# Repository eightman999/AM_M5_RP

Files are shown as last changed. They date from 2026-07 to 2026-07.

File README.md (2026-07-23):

# AM_M5_SEN0628_x3_0pm50_CorridorAvoid

M5StickC Plus + Arduino Mega + SEN0628(8x8 ToF)x3 + BMA400 構成の、通路追従・障害物回避スキッドステアロボット。

## 概要

- 前方/左右(0°, +50°, -50°)に取り付けた3基のSEN0628(8x8マトリクスToF)で周囲を計測し、
  M5StickC Plus側で回避・通路中央維持・コーナー旋回を判断する。
- 駆動はArduino Megaが担当し、M5からUART経由で受け取った左右デューティ指令を
  L298N経由でモーターに出力する(500HzソフトウェアPWM、キック/ランプ制御付き)。
- M5側はWi-Fi SoftAPで点群・姿勢・加速度をUDP配信し、PC側の`tools/point_cloud_viewer.py`で
  リアルタイムに可視化(点群マップ・推定軌跡・ステータス表示)できる。

## ハードウェア構成

### 主要部品

| 部品 | 役割 |
|---|---|
| M5StickC Plus | メイン制御(判断・IMU・センサー統合・Wi-Fi配信) |
| Arduino Mega | モーター駆動専用(L298N制御、500Hz PWM) |
| SEN0628 (DFRobot 8x8 ToF) x3 | 前方/左右の距離計測(TCA9548A経由) |
| TCA9548A | I2Cマルチプレクサ(センサー3基+BMA400をチャンネル分離) |
| BMA400 (Seeed Grove, ±16g) | 補助加速度計(TCA CH0)。M5内蔵IMUとブレンドして点群ビューアーの位置推定に使用 |
| L298N | モータードライバ |

`robot-parts-all.3mf` / `robot-parts-all.stl` に3Dプリント用の車体パーツ一式が入っている。

### 配線

**TCA9548A チャンネル割当**(実機確認済み):

| チャンネル | 接続先 |
|---|---|
| CH0 | BMA400 (Grove, I2C 0x15) - コネクタは車体後ろ向き |
| CH1 | SEN0628 front (0°, 中央) |
| CH2 | SEN0628 left (+50°, ひだり) |
| CH3 | SEN0628 right (-50°, 右) |

**M5StickC Plus側I2Cバス**(2系統を`Wire.begin()`の切り替えで使い分け):

| バス | ピン | 用途 |
|---|---|---|
| 内蔵(body) | SDA=21, SCL=22 | M5内蔵IMU(MPU6886) |
| 外部(external) | SDA=32, SCL=33 | TCA9548A(SEN0628 x3 + BMA400) |

**M5 ⇔ Mega UART**(115200bps):

```
M5 GPIO26 TX  -> AM D19 RX1
AM D18 TX1    -> level shifter/divider -> M5 GPIO36 RX
GND common
```

**Mega ⇔ L298N**:

```
L298N IN1 -> AM D22 / PA0
L298N IN2 -> AM D23 / PA1
L298N IN3 -> AM D24 / PA2
L298N IN4 -> AM D25 / PA3
```

## ソフトウェア構成

| ファイル | 対象 | 内容 |
|---|---|---|
| `M5_AM_SEN0628_3xSEN0628_v15/M5_AM_SEN0628_3xSEN0628_v15.ino` | M5StickC Plus | センサー統合・判断ロジック・モーター指令送信・UDP点群配信(v23時点) |
| `AM_HighTorqueAntiStall_500HzPWM_NoJumper_v4_for_x3/AM_HighTorqueAntiStall_500HzPWM_NoJumper_v4_for_x3.ino` | Arduino Mega | モーター駆動専用(500Hz PWM、キック/ランプ、UARTでM5から受信)(v2時点) |
| `tools/point_cloud_viewer.py` | PC(Python) | UDP点群・IMU/加速度・推定軌跡・キャリブレーション進行状況のリアルタイム可視化ツール |
| `PARAMETERS.md` | - | 全チューニング定数の意味・調整効果の詳細解説 |

ファイル名の`_v15`/`_v4`はスケッチ内の初出バージョンを指すが、実際の版数は各ファイル冒頭の
changelogコメント(現時点でM5側はv23、Mega側はv2)を参照すること。

### 通信プロトコル(UDP点群配信)

- SoftAP: SSID `M5_POINT_CLOUD` / パスワード `m5pointcloud` / ポート `4210`
- フレームは`PCLD`マジック+CRC16-CCITT付きバイナリ。`version`フィールドで後方互換:
  - v1: 距離・姿勢の基本情報のみ
  - v2: + M5内蔵IMU加速度、センサー個別ヨー/タイムスタンプ
  - v3: + BMA400(TCA CH0)加速度。M5内蔵IMUと単純平均でブレンドして位置推定に利用
  - v4: + キャリブレーション(BtnB)の進行状況(`trimMilli`/`calRound`/`calPass`/`calDriftCdeg`)。
    `driveState`に`DS_CALIBRATING(3)`を追加し、キャリブ中はPC側ビューアーの
    「CALIBRATION」パネルにラウンド/パス/ドリフト/トリムをリアルタイム表示する
- 詳細なフィールド定義は`tools/point_cloud_viewer.py`の`PointCloudFrame`/`decode_frame()`、
  および送信側は`.ino`の`PointCloudFrame`構造体/`streamPointCloud()`を参照。

## セットアップ

### 必要なArduinoライブラリ

- M5StickCPlus
- DFRobot_MatrixLidar (SEN0628用)
- Seeed_BMA400 (`https://github.com/Seeed-Studio/Grove_3Axis_Digital_Accelerometer_BMA400`)
- 標準搭載: Wire, Preferences, WiFi, WiFiUdp

### 書き込み手順

1. `M5_AM_SEN0628_3xSEN0628_v15/M5_AM_SEN0628_3xSEN0628_v15.ino` をM5StickC Plusへ書き込み。
2. `AM_HighTorqueAntiStall_500HzPWM_NoJumper_v4_for_x3/AM_HighTorqueAntiStall_500HzPWM_NoJumper_v4_for_x3.ino` をArduino Megaへ書き込み。
3. 起動時、M5のLCDにセンサー初期化状況(SEN0628 3基、BMA400)が順に表示される。
   `not found` / `NG` 表示が出た場合は配線・TCAチャンネルを確認する。

### PC側ツールの実行

```
python3 tools/point_cloud_viewer.py
python3 tools/point_cloud_viewer.py --self-test   # ユニットテスト(プロトコルデコード・デッドレコニング)
```

PCをM5の SoftAP(`M5_POINT_CLOUD`)に接続してから起動する。追加の依存パッケージは無し(標準ライブラリのみ、tkinter必須)。

## 操作方法

- **BtnA**: IMUゼロ点校正 → 走行開始
- **BtnB**(停止中のみ): 直進キャリブレーション(v18)。短いパス(約3.3秒)を3回走って
  中央値ドリフトから左右モーター差(motorTrim)を算出しNVSへ保存。`CAL_OK_DEG`に収まるまで
  最大12ラウンド自動継続し、ラウンド間は「Reposition robot / B:continue A:stop」表示で
  ロボットを開始位置へ戻すよう案内する(後方無センサのため自動バックはしない)
- **BtnA+BtnB**(待機中): `drive`名前空間のNVSを初期化し、保存済みmotorTrimを0へ戻す
- 走行中はIMU方位維持+距離センサーによる連続ステア回避(v20)/バック/通路中央維持を自動判断。
  常に前進し続け、超信地旋回(その場旋回)は行わない
- LCDに状態(FORWARD/BACK)、理由、距離、トリム値などをリアルタイム表示

## 既知の課題・未検証事項

- **BMA400の軸対応**: コネクタが車体後ろ向きという情報とSeeed製品ページの座標系図から
  X=車体右/Y=車体前方と結論づけたが、実機での重力方向テスト(静止時Z≒+1000mg等)による
  裏取りはまだ行っていない。
- **M5側ファームウェア(BMA400関連コード)は実機コンパイル・書き込み未検証**
  (開発環境にArduino向けビルドツールチェーンが無いため、構文レビューのみ)。
- **v20: 超信地旋回(PIVOT)を全廃止し、常時前進+連続ステア(目標ヨーの連続バイアス)のみで
  回避する方式に変更した。実機での回避挙動確認はまだ行っていない。** 差動ステアは
  `HEADING_CORR_LIMIT`で頭打ちになるため、旧来のその場旋回よりも実効的な旋回半径が
  大きく、狭いコース・直角コーナーでは壁に接触するリスクがある。これに合わせて
  `FWD_CMD`/`FWD_SLOW_CMD`も減速したが、それでも足りない場合はさらなる調整が必要
  (詳細はPARAMETERS.md 1.4節参照)。低速・監視下での初回テストを推奨する。
- **v22: 上記の懸念(前方に壁が迫った時に曲がりきれない)への対策として、前方が実際に危険域
  (frontRed)の間だけ片輪を止める急旋回(タンクターン、逆転はしない)を追加した。実機での
  効き確認はまだ行っていない。**
- **v23: ユーザーフィードバックによる調整。** (1) WiFiはv21で試した既存WiFi(STA)接続を撤回し
  SoftAP方式に戻した(学校WiFi等、認証情報を書き込むのが望ましくない環境を考慮)。
  (2) 走行速度をさらに減速(`FWD_CMD` 180→165, `FWD_SLOW_CMD` 165→155)。
  (3) キャリブレーション中の前方ToFスペースチェックを廃止し、パスは常にフル尺で走る
  (コース長は運用者側で確保する前提)。(2)(3)とも実機での効果確認はまだ行っていない。
- **点群ビューアーのデッドレコニング**: v20でピボット自体が無くなったため「ピボット中は
  並進ゼロ扱い」のロジックは通常到達しなくなったが、コード自体は残っている(無害)。
  それとは別に、絶対位置補正(スキャンマッチング/ICP等)は引き続き未実装で、
  IMU/加速度ドリフトが蓄積する点は変わらない。
- **v16で変更したキャリブレーションゲイン**(`CAL_TRIM_GAIN`, `AUTO_TRIM_RATE`)は
  静的コードレビューに基づく変更で、実走行での再調整前提(詳細はPARAMETERS.md参照)。
- **v18の複数パス平均・自動ラウンド継続キャリブレーションは実機での収束確認がまだ**。
  1ラウンドの合計走行距離は旧来の単発10秒とほぼ同じになるよう設計したが、
  実際のコース長で問題なく収まるかは要確認。
- **v19のキャリブレーション情報UDP配信・点群ビューアーのCALIBRATIONパネルも実機未検証**
  (Pythonデコード側はセルフテスト済みだが、M5側からの実送信・表示は未確認)。
- センサー高さ・車体の静止傾き(前方1〜2度上向き)による遠方誤判定の可能性は理論上残っている
  (実測での数値補正は未実装)。

## 詳細パラメータ

各定数の意味・調整時の挙動変化・相互依存関係は [PARAMETERS.md](PARAMETERS.md) を参照。

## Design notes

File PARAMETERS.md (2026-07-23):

# パラメーター解説

対象:
- `M5_AM_SEN0628_3xSEN0628_v15/M5_AM_SEN0628_3xSEN0628_v15.ino`（M5StickC Plus, 判断・センサー統合側, v16時点)
- `AM_HighTorqueAntiStall_500HzPWM_NoJumper_v4_for_x3/AM_HighTorqueAntiStall_500HzPWM_NoJumper_v4_for_x3.ino`（Arduino Mega, モーター駆動側, v2時点)

値はソース内の定義そのまま。**「調整の効果」列は挙動の傾向を説明するものであり、数値の正しさは実走行で確認すること。**特に「テスト値+40mm」と注記のある距離閾値は、卓上ベンチテストの実測値に安全マージンを足した運用値であり、コース(壁間隔・障害物サイズ)が変わればテストからやり直す前提。

---

## 1. M5側 (M5StickC Plus)

### 1.1 通信・センサー基本設定

| 定数 | 値 | 意味 | 調整の効果 |
|---|---|---|---|
| `AM_UART_BAUD` | 115200 | M5⇔Mega間UARTのボーレート | Mega側`Serial1.begin(115200)`と必ず一致させる |
| `TCA_ADDR` | 0x70 | I2Cマルチプレクサ(TCA9548A系)のアドレス | 実機のTCAアドレスが異なれば要変更 |
| `SEN_COUNT` | 3 | SEN0628の搭載数 | 増減時は`SEN_CH`/`SEN_ANGLE_DEG`/`senDev`配列も要同時変更 |
| `SEN_CH` | {1,2,3} | 各センサーのTCAチャンネル番号(front/left/right) | 実機配線に合わせる(CH0はBM予約で未使用) |
| `SEN_ANGLE_DEG` | {0, +50, -50} | 各センサーの水平マウント角(車体前方基準) | 前方/側方への幾何投影(`senCosAbs`/`senSinAbs`)に直結。実機取付角とズレると全ての距離判定が狂う |
| `SEN0628_ADDR` | 0x33 | SEN0628本体のI2Cアドレス | センサー側設定変更時のみ変更 |
| `POLL_SEQ` | {0,1,2,0,1,2} | センサーのポーリング順(v16: 前方偏重4:2:2→均等1:1:1に変更) | 増やす=そのセンサーの鮮度が上がる。前方の比率を下げすぎると`SENSOR_STALE_MS`との兼ね合いで前方安全マージンが減る可能性 |
| `AM_COMMAND_PERIOD_MS` | 16 | Megaへモーター指令を送る最小間隔 | 短くすると指令送信頻度は上がるが`sendDriveCommandSmooth`のslewは別途`CMD_SLEW_PER_SEND`で制御される |
| `AM_TIMEOUT_MS` | 300 | Megaからのテレメトリが途絶えたと判断するまでの時間 | Mega側`TELEMETRY_PERIOD_MS`(35ms)より十分大きく保つこと |
| `TEST_MODE` | false | 加速度診断(衝撃検知等)の計算・表示を有効化するフラグ | trueにすると`lastImpactG`等がTEST_MODE時のみ計算される(実走行の判断には使われない、表示専用) |

### 1.2 車体形状・安全マージン

| 定数 | 値 | 意味 | 調整の効果 |
|---|---|---|---|
| `BODY_FRONT_MARGIN_MM` | 40 | 前方の当たり判定余裕(表示・内訳用) | 実際の閾値は各`FRONT_*_MM`に直接明示されているため、この値自体は現状ドキュメント的な意味合いが強い |
| `BODY_SIDE_MARGIN_MM` | 25 | 側方の当たり判定余裕(表示・内訳用) | 同上 |
| `EXTRA_SAFETY_MM` | 20 | 不確実性ぶんの追加余裕(表示・内訳用) | 同上 |
| `SENSOR_TO_TIRE_OUTER_MM` | 50 | 左右センサー位置からタイヤ外端までの張り出し | `sideClearanceMm()`でこの分を差し引いてタイヤ外端基準のクリアランスに変換。実車体で測り直した値に更新すること |

### 1.3 走行速度

| 定数 | 値 | 意味 | 調整の効果 |
|---|---|---|---|
| `FWD_CMD` | 155（v42: 140→155） | 通常前進の最大デューティ | 幅約1mのコースに合わせて一段増速 |
| `FWD_SLOW_CMD` | 135（v42: 120→135） | 減速時の下限デューティ | 回避距離を同時に拡大したうえで一段増速 |
| `MIN_MOVING_CMD` | 110（v26: 140→110） | 前進の正方向指令の最低デューティ(底上げ) | Mega側`MIN_EFFECTIVE_CMD`(100)に10の余裕を持たせた |
| `MAX_MOVING_CMD` | 252 | 送信可能な最大デューティ(飽和防止で255未満) | キャリブ走行(`CAL_DRIVE_CMD`)にも使われる |
| `TURN_CMD` | 210（v28新規） | 前方赤時の片輪停止旋回専用出力 | 通常減速値120では避けきれなかったため強化。片輪停止旋回では`motorTrim`を適用しない |
| `CLOCKWISE` | true（v33新規） | 四角での周回方向 | `true`なら時計回り＝右90°、`false`なら反時計回り＝左90° |
| `CORNER_TURN_DEG` | 90°（v33新規） | 四角検知時のIMU目標旋回角 | 旋回開始時ヨーから設定方向へ90° |
| `CORNER_TURN_DONE_DEG` | 5° | 90°旋回の終了許容差 | 目標まで5°以内で旋回完了 |
| `CORNER_CONFIRM_MS` / `CORNER_CONFIRM_FRAMES` | 200ms / 2フレーム（v34新規） | 前方赤を四角として確定する条件 | 同じキャッシュ値だけでは確定せず、異なる前方測距フレームが2回連続で赤かつ200ms継続した場合のみ90°旋回する |
| `CORNER_FRONT_X_MIN_MM` / `MAX` | 70mm / 320mm（v35新規） | 幾何四角判定で前方壁を探す車体前方範囲 | 各点を`x=L*cos(theta)`へ変換して探索 |
| `CORNER_FRONT_MIN_SPAN_MM` / `MIN_POINTS` | 140mm / 8点 | 前方を横切る壁とみなす最小横幅・点数 | 細い障害物や単発点を四角から除外する |
| `CORNER_FRONT_Y_BIN_MM` / `MIN_CONTIGUOUS_MM` | 50mm / 400mm（v36新規） | 前方壁として必要な横方向の連続占有幅 | 最大幅300mmの障害物前面を除外する。障害物の左右に後壁が見えても中央の欠落で連続判定が分断される |
| `CORNER_SIDE_MIN_SPAN_MM` / `MIN_POINTS` | 50mm / 6点（v37: 100→50） | コーナー外周側壁とみなす最小前後長・点数 | 幅1m中央では外周壁が約400mm横にあり、前方壁直前で視野に入る側壁長が約58mmになるため |
| `CORNER_SIDE_Y_MIN_MM` / `MAX` | 80mm / 600mm（v37: 上限380→600） | 幾何四角判定で外周側壁を探す左右距離範囲 | 幅約1mのコース中央から見える約400〜500mm先の外周壁を含める |
| `COURSE_RETURN_DONE_DEG` / `COURSE_RETURN_TIMEOUT_MS` | 3° / 2000ms（v34新規） | 通常回避後に元の直進方位へ戻す終了条件 | 3°以内へ戻るか2秒経過で復帰処理を終了する。90°コーナー旋回には適用しない |
| `CENTER_OBS_SCORE_DELTA_MAX` | 15（v43新規） | 中央障害物とみなす左右危険スコアの最大差 | 左右がほぼ同程度に見える前方障害物だけを対象にする |
| `CENTER_OBS_CLEARANCE_DELTA_MAX_MM` | 50mm（v43新規） | 中央障害物とみなす左右クリアランスの最大差 | L字でなく左右差50mm以内なら周回設定方向へ固定回避する |
| `VEHICLE_WIDTH_MM` | 300mm（v44新規） | 中央障害物回避時の通過可否基準 | 規定旋回側が300mm未満で、反対側に300mm以上あれば反対側へ回避する |
| `SEN_SIDE_DANGER_MM` / `SEN_SIDE_WARN_MM` | 130mm / 230mm（v45新規） | 左右8x8点群専用の危険・警戒値 | 前方用160/280mmと分離し、前方の半透明板感度を維持する |
| `FORCE_BACK_MS` / `BACK_CLEAR_CONFIRM_MS` | 3000ms / 300ms（v46） | 通常バック時間と、バック後の前方安全確認時間 | 3秒終了時も前方赤なら停止を維持し、赤解除が300ms続くまで前進しない |
| SEN0628 `raw[64]`読取バッファ | 毎フレーム全セルを0クリア（v47） | 未更新セルの前回値を無効化 | `getAllData()`前に消去し、残留した近距離値による赤判定を防ぐ |
| `SEN_FRONT_ROW_FIRST` / `SEN_FRONT_ROW_LAST` | row 1〜3（v48） | 前方センサーの走行判定使用行 | 床側に映るrow 4〜5を前方の赤・バック判定から除外する。左右はrow 2〜5を維持 |

### 1.4 連続ステア回避判定(v20: 超信地旋回を全廃止)

v16まではLCD赤判定/距離閾値で超信地旋回(その場で停止して回転)を開始し、IMU旋回角で終了判定する
方式だった。v20でこれを全廃止し、**常に前進しながら**危険度スコア(0-100)に応じて目標ヨー
(`targetYawDeg`)を連続的に「広い側/安全な側」へバイアスする方式に一本化した。実際の差動出力は
既存の`headingCorrection()`(±`HEADING_CORR_LIMIT`)がそのまま担うため、新規の差動計算は無い。

| 定数 | 値 | 意味 | 調整の効果 |
|---|---|---|---|
| `STEER_MAX_DEG` | 35°（v20新規） | 最大緊急度(avoidUrgency=100)でのヨーバイアス量 | `HEADING_CORR_LIMIT`(28)を飽和させる値に設定(35×`HEADING_KP`1.30=45.5>28)。下げると最大回避時の実効差動が弱まる |
| `STEER_URGENCY_MIN` | 15（v25: 18→15） | このスコア(0-100)未満は回避バイアスをかけない(通常走行/通路中央維持のみ) | v25で小さな左右差へ少し早く反応するよう変更 |

方向選択の優先順位(v16の考え方を継承): (1) 片側だけ危険(スコア≧`OBSTACLE_RED_SCORE`)なら必ず反対へ、
(2) `leftClear`/`rightClear`の差が`CLEARANCE_DIR_BIAS_MM`を超えれば広い側へ、(3) スコア差があれば
危険度が低い側へ、(4) 判断材料が無ければ直前にステアした方向(`lastSteerDir`)を維持。

**旧`DS_BACK`(前方極近の緊急バック)は維持。** v27以降は前・左・右のスコアがすべて
`OBSTACLE_RED_SCORE`以上になった場合も、空いている旋回方向がないため即バックする。
直前のバックから`BACK_COOLDOWN_MS`以内に三方向赤が続いている場合は、前進へ戻らず
`ALL_RED_WAIT`で停止し、クールダウン後も三方向赤なら再度バックする。
バック終了後はピボットせずそのまま前進へ戻り、
連続ステアが自然に避ける前提。バック時にどちらが広かったかは`backRecoverDir`として
`lastSteerDir`の初期値に使われる。

v33以降、前方赤を四角到達として、`CLOCKWISE`で指定した方向へIMU基準で90°旋回する。
三方向赤の場合は同じ設定方向へ2000msカーブバックしてから90°旋回へ接続する。
LCD reasonは時計回りなら`BACK_ARC_R`→`CORNER_R`、反時計回りなら
`BACK_ARC_L`→`CORNER_L`と遷移する。前方極近だけの通常BACKも3000msの直線後退を行う。
カーブバック前のヨーから最終90°目標を固定するため、バック中に回った角度を含めた
合計旋回量が90°になる。バック終了角から追加で90°回すことはない。

v35以降は中央4行の各点を`x=L*cos(theta), y=L*sin(theta)`で車体座標へ変換する。
v36以降は前方を横切る点群が横方向へ400mm以上連続する壁と、
周回方向外側に続く前後長50mm以上の側壁が
推定交点で接続するL字形状を四角候補とする。さらに異なる前方測距フレーム2回と200ms継続の
両条件を満たした場合だけ90°旋回する。それ以外は通常回避として扱う。
通常回避では開始前の直進ヨーを保存し、障害物消失後に`RETURN`状態でその角度へ戻る。

v43以降、L字形状ではなく、左右スコア差15以内・クリアランス差50mm以内の前方赤は
`CENTER_OBSTACLE`とする。時計回りなら右、反時計回りなら左へ35°まで変針しながら前進し、
通過後は`RETURN`で元の直進方位へ戻る。90°コーナーTURNには入らない。

**実機での回避挙動確認はまだ行っていない。** 超信地旋回よりその場での方向転換能力が大幅に
落ちる(差動ステアの実効旋回半径は`HEADING_CORR_LIMIT`とFWD速度で決まり、その場旋回よりずっと大きい)
ため、狭いコース・直角コーナーでは壁に接触するリスクがある。上記のFWD_CMD/FWD_SLOW_CMD減速は
その対策だが、それでも足りない場合はさらなる減速、`STEER_MAX_DEG`/`STEER_URGENCY_MIN`の調整、
または`HEADING_CORR_LIMIT`自体の引き上げを検討すること。

**v22: 前方タンクターン(frontRed時のみ)。** 上記の懸念(継続ステアだけでは前方の壁を
曲がりきれない)への対策として、`frontScore >= OBSTACLE_RED_SCORE`(=frontRed)の間だけ、
片輪を0、もう片輪を`TURN_CMD`にする急旋回(タンクターン)を優先実行する。逆転はしない
(超信地旋回はしない)ため「常に前進」の方針とは矛盾しない。前方が危険域を脱するとreason:
`TURN_L`/`TURN_R`(両側危険なら`ESCAPE_L`/`ESCAPE_R`)から自然に(2)の継続ステアまたは
通常前進へ戻る。専用の定数(タイムアウト・角度目標等)は無く、`frontRed`が続く限り
毎周期このタンクターンを再評価するだけの単純な仕組み。**実機での効き確認はまだ行っていない。**

### 1.5 前方/側方の距離閾値

| 定数 | 値 | 意味 | 調整の効果 |
|---|---|---|---|
| `FRONT_SLOW_MM` | 320mm（v42: 200→320） | 前方がこの距離未満で減速開始 | 増速と半透明板の弱反射を考慮し、早めに減速 |
| `CLEARANCE_DIR_BIAS_MM`| 20mm（v16新規） | 前方回避ピボットの方向選択で「クリアランスが広い側」を優先する際の最小差 | 小さくするとわずかな差でも方向選択に反映されやすくなる(センサーノイズで方向がぶれるリスクも増える) |
| `FRONT_STOP_MM` | 60mm | 前方センサー実測の最小値がこの距離未満でBACK発動 | BACKの唯一のトリガー(v15でIMU衝撃トリガーは削除済み) |
| `FRONT_HARD_MM` | 180mm（v42: 120→180） | 前方危険スコアが100%になる距離 | 半透明板へ余裕を持って強く反応 |
| `FRONT_WARN_MM` | 280mm（v42: 180→280） | 前方危険スコアが0%になる距離 | 180〜280mmで連続的に回避を強める |
| `SIDE_DANGER_MM` / `SIDE_WARN_MM` | 160mm / 250mm（v45） | 側方(投影)距離の危険/警戒境界 | 幅1mコースで左右が常時赤になるのを抑える |
| `SEN_DANGER_MM` / `SEN_WARN_MM` | 160mm / 280mm（v42） | SEN0628個別セルの危険/警戒境界 | 半透明板の少数戻りを遠めからスコアへ反映する |
| `SEN_DANGER_NEAR_COUNT` / `SEN_WARN_NEAR_COUNT` | 3 / 3 | 上記境界を超えるセル数がこの数以上でスコアを強制的に引き上げ | 下げるとノイズ1セルでも過敏に反応、上げると鈍感になる |
| `SEN_EDGE_NEAR_COUNT` | 2（v30新規） | 各8x8センサーの左右端2列で危険/警戒と判定する最小セル数 | 視野の継ぎ目と細い障害物は占有セルが少ないため、全体判定の3セルより早く反応させる |
| `SEN_ACTIVE_ROW_FIRST` / `SEN_ACTIVE_ROW_LAST` | 2 / 5（v31新規） | 障害物判定に使う8x8の縦方向行範囲 | 床・車体を拾いやすい上下各2行を走行判断から除外し、中央4行だけを使用する。raw取得と点群配信は全8行を維持 |
| `OBSTACLE_RED_SCORE` | 60（v28: 70→60、3/5） | LCD赤表示および実際の回避開始と共通のスコア閾値 | より遠い位置から赤判定・回避を開始する |

v30以降、前方センサーは中央6列だけでなく全8列を回避判定へ使用する。また3基すべてで
左右端2列を専用集計し、警戒距離内が2セル以上なら最低65点、危険距離内なら最低90点とする。
これによりセンサー視野の端・継ぎ目にだけ映った障害物も赤判定へ到達する。

さらに点群ビューアーと同じ水平角モデル
`SEN_ANGLE_DEG[sensor] + 26.25° - col×7.5°`で全192セルを展開し、前方
`-32〜+32°`、左`+18〜+80°`、右`-80〜-18°`へ重なり付きで再集計する。
前方と左右を14°重ねるため、3基の物理視野が約10°重なる部分も複数方向の回避判断へ反映される。
v31以降、この角度統合を含む障害物判定は中央4行(row 2〜5)だけを使用する。
上下端行のデータは診断用raw/点群には残るが、モーター制御には影響しない。
| `SEN_LOW_VALID_CAUTION_SCORE` | 50（v42: 40→50） | 有効測距点が少ない場合の最低スコア | 半透明・低反射対象で有効セルが減った場合も強めに減速する |
| `SEN_MOUNT_OFFSET_MM` | 0 | センサー取付面の凹み等の微調整用オフセット | v10で水平マウント化により上向きチルト補正は廃止。通常0のままでよい |

### 1.6 モーター左右差キャリブレーション

| 定数 | 値 | 意味 | 調整の効果 |
|---|---|---|---|
| `CAL_DRIVE_CMD` | `MAX_MOVING_CMD`(252) | BtnBキャリブ走行時の指令値(最大速度で差を計測) | 低速では非線形なズレが出るため意図的に最大速度固定 |
| `CAL_DRIVE_MS` | 10000ms | 1ラウンドの合計走行時間(旧来の単発10秒と同じ基準。v18でパス分割の正規化基準にも使用) | 長くすると測定精度は上がるが、コースの直線区間長に制約される |
| `CAL_PASSES_PER_ROUND`（v18新規） | 3 | 1ラウンドをこの回数の短いパスに分割し、中央値で外れ値を除去 | 増やすほどノイズに強くなるが1ラウンドの所要時間(パス間の待機込み)が伸びる |
| `CAL_PASS_DRIVE_MS`（v18新規） | `CAL_DRIVE_MS / CAL_PASSES_PER_ROUND`（約3333ms） | 1パスあたりの走行時間 | 1ラウンドの合計走行距離が旧来の単発10秒とほぼ同じになるよう自動計算。**v23でパスは必ずこの時間いっぱいまで走る(前方ToFによる早期中断は廃止)** |
| `CAL_PASS_MIN_VALID_MS`（v18新規） | `CAL_PASS_DRIVE_MS / 2`（約1666ms） | これ未満で中断したパスは無効 | v23現在はBtnA中断以外でこれより短くなることは無い想定(理論上の保険として残存) |
| `CAL_MAX_ROUNDS`（v18新規） | 12（v23: 5→12） | `CAL_OK_DEG`に収束しない場合の自動打ち切り上限ラウンド数 | trim=0から`TRIM_LIMIT`(0.34)まで自動収束しきれるよう拡大。増やすほど収束を粘れるが、収束しない個体差(ハード非対称)の発見が遅れる |
| `CAL_TRIM_GAIN` | 0.005（v16: 0.0035→0.005） | ヨードリフト1°あたりのトリム修正量 | 初回キャリブの収束を早めるため引き上げ。大きすぎると1回のキャリブで行き過ぎる(オーバーシュート)リスク |
| `TRIM_LIMIT` | 0.34（v23: 0.25→0.34） | `motorTrim`の絶対値上限 | 送信式`sendL=left*(1-trim), sendR=right*(1+trim)`より実効左右比は`(1+trim)/(1-trim)`。**モーター個体差を最大2倍と仮定**し、`(1+T)/(1-T)=2`を解いたT=1/3に余裕を見て0.34(比2.03倍まで補正可能)。それでも張り付く場合はハード側(モーター/ギア/配線/摩擦)の非対称を直接疑う |
| `CAL_OK_DEG` | 4° | この範囲のドリフト(中央値)なら「CAL OK」表示(合格) | 厳しくする(小さくする)と収束までのラウンド数が増えやすい |
| `AUTO_TRIM_ENABLE` | false（v29: true→false） | 走行中の`motorTrim`自動微学習 | NVSに保存されたBtnBキャリブ結果だけを通常走行でもそのまま使うため無効化 |
| `AUTO_TRIM_RATE` | 0.00020（v16: 0.00004→0.00020） | 走行中の自動学習率(ヘディング補正量1あたり/周期) | 収束が遅すぎた旧値から5倍に引き上げ。振動的(ふらつき)になるようなら下げること |
| `TRIM_SAVE_PERIOD_MS` | 20000ms | 自動学習分をNVSへ定期保存する間隔 | 変化(差0.01超)があった時のみ実際に書き込む |

**v18のキャリブレフロー**: BtnB押下 → 1ラウンド(`CAL_PASSES_PER_ROUND`回の短いパス、パス間300ms待機)
→ 中央値ドリフトから`motorTrim`更新 → `CAL_OK_DEG`未満なら完了。未収束なら「Reposition robot / B:continue A:stop」表示で
ロボットを開始位置へ戻すよう要求し、BtnBで次ラウンドへ(後方無センサのため自動バックはしない)。
`CAL_MAX_ROUNDS`到達で「NOT CONVERGED」表示して終了。パス中にBtnA押下で即座にキャリブ全体を中止する。
**v23: 前方ToFによるコース不足チェックは廃止したため、コース長は運用者側で確保されている前提。**
**実機での収束確認・所要時間感はまだ検証していない。**

**v19: キャリブ情報のUDP配信**: `runStraightCalibration()`/`runOneCalPass()`実行中は
`dstate = DS_CALIBRATING`(値3)にし、`calStreamRound`/`calStreamPass`/`calStreamDriftDeg`を
更新しながら`streamPointCloud()`を呼ぶ(点群フレームプロトコルはv4に拡張、`trimMilli`/`calRound`/
`calPass`/`calDriftCdeg`フィールドを追加)。PC側`point_cloud_viewer.py`はCALIBRATIONパネルに
これをリアルタイム表示する。**実機でのM5→PC送信・表示は未検証(Python側デコードはセルフテスト済み)。**

### 1.7 バック(後退)判定

| 定数 | 値 | 意味 | 調整の効果 |
|---|---|---|---|
| `BACK_L_CMD` / `BACK_R_CMD` | -215 / -215 | バック時の左右デューティ | 前進と同じ大きさ・両輪逆転で直線バック |
| `FORCE_BACK_MS` / `CORNER_BACK_MS` | 3000ms / 1600ms（v46） | 前方極近の直線バック／コーナー脱出カーブバックの継続時間 | コーナーは後退しすぎによる90°旋回後の引っ掛かりを抑え、通常バックは最低3秒を維持 |
| `BACK_ARM_DELAY_MS` | 1200ms | 起動直後、BACKトリガーを有効化するまでの待機時間 | 起動時の強いトルク/通常加速をBACKと誤認しないための猶予(v15以降はBACKは距離センサーのみがトリガーなので、これは主に「起動直後の意図しない挙動」全般への保険) |
| `BACK_COOLDOWN_MS` | 2000ms | バック完了後、再バックまでの最短間隔（**v16でバグ修正: 以前は論理式の誤りで無効化されていた**） | 短くすると連続バックが起きやすくなる。長くすると本当に詰まった状況で再バックまで待たされる |
| `KICK_IGNORE_MS` | 450ms | 発進キック直後、衝撃検知を無効化する時間(TEST_MODE時のみ意味を持つ) | 実走行(TEST_MODE=false)には影響しない |

### 1.8 通路(コリドー)追従

| 定数 | 値 | 意味 | 調整の効果 |
|---|---|---|---|
| `CORRIDOR_MIN_WALL_MM` / `CORRIDOR_MAX_WALL_MM` | 55mm / 420mm（v37: 上限260→420） | この範囲のタイヤ外端基準クリアランスなら「壁」とみなす | 実コース幅約1000mm、車幅約300mmから中央時のタイヤ外端クリアランスを片側約350mmと算出し、測距・姿勢余裕を含めた上限 |
| `CORRIDOR_DETECT_SCORE` | 25 | 距離レンジ外でもこのスコア以上なら「壁」とみなす(距離判定の補完) | 下げると壁認定が緩くなる |
| `CORRIDOR_DIFF_DEADBAND_MM` | 30mm（v16: 50→30） | 左右クリアランス差がこの範囲内なら中央維持の舵を入れない(不感帯) | 縮小して中央維持精度を上げた。小さくしすぎるとセンサーノイズで小刻みに舵が入り続ける可能性 |
| `CORRIDOR_YAW_STEP_DEG` | 0.35°/周期 | 1制御周期あたりの目標ヨー移動量の最大 | 上げると中央寄せの反応が速くなるが、ノイズに敏感になる |
| `CORRIDOR_YAW_CLAMP_DEG` | 22° | 目標ヨーが現在ヨーから離れすぎないための制限 | `HEADING_CORR_LIMIT`との整合を考慮すること |
| `CORRIDOR_MISS_STREAK_LIMIT` | 3（v16新規） | corridorModeのヒステリシス: 連続何回未検知が続いたら実際に解除するか | 瞬間的な障害物検知でのフリッカーを防止。上げるとより粘り強くcorridorModeを維持するが、本当に壁がなくなった時の切替も遅れる |

### 1.9 IMU/ヘディング補正

| 定数 | 値 | 意味 | 調整の効果 |
|---|---|---|---|
| `HEADING_KP` | 1.30（v25: 1.15→1.30） | ヘディング誤差(目標ヨー-現在ヨー)に対する比例ゲイン | v25で左右ステアの追従を鋭敏化 |
| `HEADING_CORR_LIMIT` | 28（v25: 22→28） | ヘディング補正量の上限(左右差指令へのクランプ) | v25で最大左右差動を拡大 |
| `IMPACT_G_THRESH` | 1.00G | 衝撃とみなす加速度閾値(TEST_MODE時のみ計算、実走行には無関係) | 実走行の判断には使われない(v15で接触保険BACKトリガーは削除済み) |
| `IMPACT_CONSECUTIVE_REQUIRED` | 3 | 上記閾値を連続何回超えたら「衝撃らしい」とみなすか(TEST_MODE時のみ) | 同上 |
| `ACCEL_WARN_G` | 0.32G | 加速度警告表示の閾値(TEST_MODE時のみ意味を持つ) | 同上 |
| `AVOID_HOLD_MS` | 280ms | 回避直後、目標ヨーを現在ヨーへリセットするまでの保持時間 | 短くすると回避直後すぐに現在方位へ切り替わる |
| `SENSOR_STALE_MS` | 620ms | センサー値をこれより古いと「無効」扱いする鮮度閾値 | `POLL_SEQ`のポーリング間隔より十分大きく保つこと。v26以降は3基のうち1基でも未初期化・測距失敗・期限超過なら、欠測を「障害物なし」とせず`SENSOR_WAIT`で停止する |

**v24: `updateIMU()`のヨー積分バグ修正。** 旧実装は`dt>=0.2s`だった回のヨー積分を丸ごとスキップ
していた(ループが一瞬詰まりdtが伸びると、その間の実回転が`yawDeg`に一切反映されない)。
ユーザー実機で「キャリブLCD表示-2.9degに対し実際は右へ5〜60度変針」という食い違いが
報告され、この仕組みが疑わしいと判断して修正。現在はdtを捨てず、上限0.5sでクランプしてから
必ず積分する。**この修正が実際の原因だったかは未確認。次回のBtnBキャリブレで確認すること。**
あわせて`runStraightCalibration()`はラウンドごとに各パスの生ドリフト値もSerial/LCDへ
出力するようにした(中央値に隠れた外れ値パスの有無を直接確認できる)。

### 1.10 コマンドスムージング

| 定数 | 値 | 意味 | 調整の効果 |
|---|---|---|---|
| `CMD_SLEW_PER_SEND` | 42.0/回 | M5側で1送信あたりに変化させる指令値の最大幅(通常時) | 小さいほど滑らか、大きいほど反応が速い。符号反転や差120超の際は内部でaggressive値(44)に切り替わる |

### 1.11a BMA400 (Grove, TCA CH0) - v17新規

| 定数 | 値 | 意味 | 調整の効果 |
|---|---|---|---|
| `BMA400_TCA_CH` | 0 | BMA400のTCAチャンネル(旧: 未使用/予約だった箇所) | 実機配線を変えたら要変更 |
| `BMA400_READ_PERIOD_MS` | 50ms | BMA400ポーリング間隔 | 点群配信間隔と同程度。短くすると読み取り頻度は上がるが外部I2Cバスの占有時間が増える |

コネクタは車体後ろ向きに実装(2026-07-22ユーザー確認)。Seeed製品ページの座標系シルク図
(Z=チップ面から手前=垂直上、Y=コネクタと反対方向、X=Y×Zの右手系)と照合すると、
水平・チップ面上向き取付の前提でX軸=車体右、Y軸=車体前方に一致するため、
`getAcceleration()`の生値(mg)はそのまま「右方向/前方向」として使っている
(符号反転・軸入替なし)。**この対応関係はWeb上の製品ページの図から導出したもので、
実機での重力方向テスト(静止時Z≒+1000mg等)による裏取りはまだ行っていない。**
PC側`point_cloud_viewer.py`ではM5内蔵IMUの加速度と単純平均でブレンドし、
どちらか片方しかフレッシュでなければそちらのみを使う(`bma_ok`フラグ判定)。

### 1.11 UI/デバッグ

| 定数 | 値 | 意味 | 調整の効果 |
|---|---|---|---|
| `DEBUG_SERIAL_OUTPUT` | false | USBシリアルへのデバッグ出力有効化 | 実走行時はfalse推奨(オーバーヘッド・ノイズ削減) |
| `DEBUG_SERIAL_PERIOD_MS` | 500ms | 上記出力の間隔 | - |
| `LCD_UPDATE_PERIOD_MS` | 80ms（v15: 250→80） | LCD再描画の間隔(状態変化時は間引かず即描画) | 短くすると滑らかだが描画負荷が上がる |
| `POINT_CLOUD_STREAM_ENABLE` | true | PC側点群可視化用UDP配信の有効化 | 不要ならfalseにしてWi-Fi/CPU負荷を減らせる |
| `POINT_CLOUD_STREAM_PERIOD_MS` | 50ms(20Hz) | 上記配信間隔 | PC側の加速度積分等に使用 |
| `POINT_CLOUD_WIFI_SSID` / `PASSWORD` | "M5_POINT_CLOUD" / "m5pointcloud" | 点群配信用SoftAPの認証情報 | 運用環境に応じて変更可 |
| `POINT_CLOUD_UDP_PORT` | 4210 | 点群配信のUDPポート | PC側受信ツールと一致させる |

（v21で既存WiFi(STA)接続方式を試したが、学校WiFi等の環境考慮のため撤回しSoftAP方式に戻した）

---

## 2. Mega側 (Arduino Mega, モーター駆動)

### 2.1 モーター出力・PWM

| 定数 | 値 | 意味 | 調整の効果 |
|---|---|---|---|
| `MOTOR_MASK` | 0x0F | PORTA下位4bit(D22-D25)をモーター制御に使用 | 配線(IN1-IN4)を変える場合のみ変更 |
| `INVERT_LEFT_MOTOR` / `INVERT_RIGHT_MOTOR` | false / false | 左右モーターの回転方向を反転 | 配線ミスで前後が逆の場合にtrueへ |
| `SWAP_LEFT_RIGHT` | false | 左右の指令そのものを入れ替え | 配線ミスで左右が逆の場合にtrueへ |
| `PWM_PERIOD_US` | 2000μs(500Hz) | ソフトウェアPWMの周期 | ファイル名の通り500Hz固定。高くすると滑らかだがCPU負荷増、低くすると音が気になる場合がある |

### 2.2 ランプ・スムージング

| 定数 | 値 | 意味 | 調整の効果 |
|---|---|---|---|
| `RAMP_PERIOD_MS` | 2ms | 指令値を1段階変化させる周期 | 短くすると追従は速いが`RAMP_UP_STEP`等との積で実質的な加速度が決まる |
| `RAMP_UP_STEP` | 20/回 | 加速時、1周期あたりの変化量 | 大きいほど加速が急峻 |
| `RAMP_DOWN_STEP` | 22/回 | 減速時、1周期あたりの変化量 | 大きいほど減速が急峻 |
| `REVERSE_ZERO_STEP` | 36/回 | 符号反転時、まず0へ向かう際の変化量 | 「必ず0を経由する」反転の速さ。大きいと0通過が速い(=反転が速くなるが急激) |
| `MIN_EFFECTIVE_CMD` | 100（v26: 132→100） | 静止摩擦に打ち勝つための最低デューティ(非ゼロ指令の底上げ) | 軽量化後の低速域を使うため引き下げ。発進時は`KICK_CMD`が別途働く |

### 2.3 キック(発進補助)

| 定数 | 値 | 意味 | 調整の効果 |
|---|---|---|---|
| `KICK_CMD` | 225 | キック中の出力デューティ | 上げると発進/転換の粘り抜けが強くなるが衝撃も強くなる |
| `KICK_MS` | 150ms | キックの継続時間 | 長くすると粘り抜けやすいが、その分高出力状態が続く |
| `KICK_COOLDOWN_MS` | 180ms | 次のキックが発動できるまでの最短間隔 | 短いと連続キックしやすくなる(ジャーキーな動きの原因になり得る、v2のバグ修正と合わせて確認) |

**v2での変更点**: `applyKickToOutput()`が`actual`の符号と`kickSign`が一致する場合のみキックを効かせるよう修正済み(符号反転の瞬間にキックが暴発しないように)。上記3定数の意味自体は変わっていないが、実際に効くタイミングが「新方向へのランプが始まった後」になった点に注意。

### 2.4 通信・安全タイムアウト

| 定数 | 値 | 意味 | 調整の効果 |
|---|---|---|---|
| `COMMAND_TIMEOUT_MS` | 720ms | M5からの指令が途絶えた場合にsoftStop()するまでの時間 | M5側`AM_COMMAND_PERIOD_MS`(16ms)より十分大きい。短すぎると通信の一時的な遅延で誤停止する |
| `TELEMETRY_PERIOD_MS` | 35ms | Megaから actualLeft/actualRight 等をM5へ送信する間隔 | M5側`AM_TIMEOUT_MS`(300ms)より十分小さく保つこと |
| `BRAKE_PULSE_MS` | 30ms | `brakeStop()`時、L298N短絡ブレーキ(全bit HIGH)を維持する時間 | 長くすると制動は強いが、モーター・ドライバへの負荷増 |
| `DEBUG_USB` | false | USBシリアルへのデバッグ出力有効化 | 実走行時はfalse推奨 |

---

## 3. パラメーター間の依存関係(要注意)

- **M5 `MIN_MOVING_CMD`(110) > Mega `MIN_EFFECTIVE_CMD`(100)**: M5側の底上げ済み指令が、Mega側の底上げを下回らないようにする関係。Mega側の値を変えたらM5側もそれに合わせて見直すこと。
- **M5 `FWD_SLOW_CMD`(120) > Mega `MIN_EFFECTIVE_CMD`(100)**: 減速時でもMega側の最低デューティを上回る。実機でストールする場合は両者を同じ幅で少しずつ上げる。
- **Mega `COMMAND_TIMEOUT_MS`(720ms) >> M5 `AM_COMMAND_PERIOD_MS`(16ms)**: 通常運用で誤タイムアウトしない十分なマージン。
- **M5 `AM_TIMEOUT_MS`(300ms) >> Mega `TELEMETRY_PERIOD_MS`(35ms)**: 同上、テレメトリ側。
- **`SEN_WARN_MM`(280) > `SEN_DANGER_MM`(160)**: `obstacleScore()`は`warnMm > dangerMm`前提の実装。逆転させると常時スコア0になるので注意。
- **`STEER_MAX_DEG`(35)×`HEADING_KP`(1.30) > `HEADING_CORR_LIMIT`(28)**: 最大緊急度で確実に`HEADING_CORR_LIMIT`を飽和させる関係。`STEER_MAX_DEG`を下げすぎると最大回避時でも差動が頭打ちにならず、常に弱い回避力しか出せなくなる。

---

## 4. 実測に基づく外部情報(参考)

- **SEN0628実仕様**(DFRobot公表値): 8x8, 視野角60°, 測距3.5m, 20-200mm域で±11-12mm精度, 最大60Hz。0°/+50°/-50°の3基構成では隣接センサー間で約10°の重なりがあり、-80°〜+80°の範囲に角度的な死角はない。
- **車体**: スキッドステア2輪+前方キャスター。SEN0628マウントはボディ156(3MF内)で車体に対し水平取付。ただし車体自体は静止時に前方が1〜2°高くなる姿勢(全センサービームが実際の水平よりわずかに上を向く)。センサー高さ・壁高さの実測値がないため数値補正は未実装。

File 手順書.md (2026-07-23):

# ロボット操作手順書

対象: `M5_AM_SEN0628_3xSEN0628_v15`(M5側 v23時点) + `AM_HighTorqueAntiStall_..._v4_for_x3`(Mega側 v2時点)

プロジェクト概要・配線・ソフトウェア構成は [README.md](README.md)、各定数の詳細は
[PARAMETERS.md](PARAMETERS.md) を参照。本書は実際に電源を入れてから走らせるまでの
操作手順に絞る。

---

## 1. 事前準備

- [ ] コース(通路)に前方の障害物が無いことを確認。特にキャリブレーション走行は
      直進で数メートル進むため、直線区間を確保する。
- [ ] Mega側・M5側それぞれの電源(バッテリー/USB)を確認。
- [ ] PCで点群ビューアーを使う場合は、M5のWi-Fi SoftAP(`M5_POINT_CLOUD`)へ
      後で接続できるようPCのWi-Fi設定を確認しておく。

## 2. 初回セットアップ(ファームウェア書き込み)

初回のみ、または.inoを変更した場合に実施。詳細はREADME.mdの「セットアップ」章参照。

1. Arduino IDEに以下のライブラリを導入:
   - M5StickCPlus
   - DFRobot_MatrixLidar
   - Seeed_BMA400 (`https://github.com/Seeed-Studio/Grove_3Axis_Digital_Accelerometer_BMA400`)
2. `M5_AM_SEN0628_3xSEN0628_v15/M5_AM_SEN0628_3xSEN0628_v15.ino` をM5StickC Plusへ書き込み。
3. `AM_HighTorqueAntiStall_500HzPWM_NoJumper_v4_for_x3/AM_HighTorqueAntiStall_500HzPWM_NoJumper_v4_for_x3.ino` をArduino Megaへ書き込み。

## 3. 起動手順

電源を入れると、M5のLCDに以下の順で初期化状況が表示される。

| 表示 | 意味 | 異常時の対応 |
|---|---|---|
| `INIT BMA400` → `OK` / `init NG` / `not found` / `TCA NG` | TCA CH0のBMA400初期化 | `not found`/`NG`でも走行自体は継続する(BMA400無しで動作)。配線・CH0接続を確認 |
| `INIT SEN` `1/3 CH1`〜`3/3 CH3` → `OK` / `not found` / `begin NG` | SEN0628(前/左/右)の初期化 | `not found`/`NG`が出たセンサーは以降無効。配線・TCAチャンネルを確認 |
| `TCA NOT` `FOUND` | TCA9548A自体が見つからない(致命的) | ここで完全停止する。I2C配線(SDA=32/SCL=33側)を確認して再起動 |
| `A: START` / `B: CAL` / `A+B: NVS RESET` / `Trim ±0.XX` | 起動完了、待機状態 | この画面が出れば操作可能 |

BMA400・SEN0628はここで失敗しても致命的ではない(該当機能が無効になるだけ)。
TCA9548A自体が見つからない場合のみ完全停止する。

## 4. キャリブレーション手順(BtnB)

**初回書き込み後、または車体・タイヤを変更した後は必ず実施する。**

1. 待機画面(`B: CAL`)でBtnBを押す。
2. `CAL STRAIGHT` / `Clear path!` / `Keep still...` が表示されている間はロボットを静止させておく
   (IMUオフセットを取得中、約1秒弱)。
3. 自動で複数ラウンドの走行が始まる。1ラウンドは短いパス(約3.3秒)×3回で構成される:
   - 各パス中は `ROUND {r} PASS {p}/3` を表示しながら最大速度で直進する。
   - パスとパスの間は約0.3秒停止する(この間に次のパスが自動で始まる。ロボットの位置は動かさない)。
4. 3パス終了後、そのラウンドの結果が表示される:

   | 表示 | 意味 |
   |---|---|
   | `R{n}: CAL OK` | ドリフト中央値が`CAL_OK_DEG`(4°)未満。収束成功 |
   | `R{n}: RETRY` | まだ収束していない。次ラウンドへ |
   | `Drift ±X.X deg (n/3)` | 中央値ドリフトと有効パス数 |
   | `Trim ±0.XXX` | 更新後のmotorTrim |
   | `CAL CANCELLED` | キャリブ中にBtnAを押して中止した場合 |

   **v23: 前方ToFによるコース不足チェックは廃止したため、各パスは必ずフル尺(約3.3秒)まで
   走行する。** コースの直線区間は運用者側で確保しておくこと(自動での早期中断はしない)。

5. `CAL OK` が出れば約2.4秒後に待機画面へ戻り、キャリブレーション完了。
6. `RETRY` の場合、`Reposition robot` / `B:continue A:stop` が表示される。
   - **ロボットを手動で開始位置まで戻す**(後方センサが無いため自動では戻らない)。
   - 戻したら **BtnB** を押して次ラウンドへ継続。
   - 中止したい場合は **BtnA** を押す(`CAL CANCELLED`表示後、待機画面へ戻る)。
7. 最大12ラウンド(v23: 5→12、モーター個体差2倍まで収束できるよう拡大)まで自動継続。
   それでも収束しない場合は `NOT CONVERGED` と表示され終了する。
   - この場合、`TRIM_LIMIT`(v23: ±0.34)に張り付いていないか確認し、張り付いていればハード側
     (モーター・ギア・摩擦の左右非対称)を疑う(PARAMETERS.md 1.6節参照)。

**v19: PC側点群ビューアーを起動していれば、キャリブレーション中も右側の「CALIBRATION」パネルに
ラウンド/パス番号・直近ラウンドのドリフト・motorTrimの値がリアルタイムに表示される
(LCDと同じ情報をPC画面でも確認できる)。**

## 5. 走行手順

**v20: 超信地旋回(その場旋回)を廃止し、常に前進しながら差動ステアだけで避ける方式に変更した。
実機での回避挙動確認はまだ行っていない。低速で、目を離さずに初回テストすること。**

1. 待機画面(`A: START`)で **BtnA** を押す。
2. `IMU ZERO` / `Keep still` の間は静止させておく。
3. `START` 表示後、自動走行が始まる(通路中央維持・障害物回避・コーナー旋回を自動判断。
   その場で完全停止して回転する超信地旋回はしないが、前方が危険域(frontRed)の間は
   片輪を止める急旋回(タンクターン、v22)で対応する)。
4. 走行中のLCD表示:
   - 状態: `RUN` / `BACK`(`PIVT`はv20で廃止)
   - 理由(`reason`): `FWD` / `FWD_CARE` / `AVOID_L` / `AVOID_R` / `TURN_L` / `TURN_R` /
     `ESCAPE_L` / `ESCAPE_R` / `BACK` / `CORRIDOR` など
     (`AVOID_*`=側方中心の危険での連続ステア中、`TURN_*`=前方が実際に危険域でのタンクターン中、
     `ESCAPE_*`=両側とも危険な状態でのタンクターン/連続ステア中)
   - Trim値、クリアランスなど
5. 走行を止めたい場合は物理的に持ち上げるか電源を切る(ソフトウェア側の緊急停止ボタンは無い点に注意)。

## 6. 点群ビューアーの使い方(PC側)

1. ロボット電源投入後、PCのWi-Fiを `M5_POINT_CLOUD` (パスワード `m5pointcloud`) に接続。
2. PCで以下を実行:
   ```
   python3 tools/point_cloud_viewer.py
   ```
3. 画面右側に状態(STATE/REASON/IMU・TARGET/CLEARANCE/MOTOR/CALIBRATION/MAP/LINK)が表示され、
   左側に点群マップ・推定軌跡・ロボットの向きが描画される。
4. `LINK`欄の `BMA400 OK`/`NG/WAIT` でBMA400の接続状況を確認できる。
   `CALIBRATION`欄はキャリブ中(STATE=CALIBRATING)にラウンド/パス/ドリフト/トリムを表示し、
   非キャリブ中は直近のtrim値のみ表示する。
5. 「マップをCSV保存」「マップを消去」ボタンで記録した点群を保存・リセットできる。
6. 動作確認だけしたい場合(実機不要):
   ```
   python3 tools/point_cloud_viewer.py --self-test
   ```

## 7. 終了手順

- ロボット・PC双方の電源/プロセスを終了するだけでよい(NVSに保存されたmotorTrimは
  次回起動時に自動復元される)。

## 8. トラブルシューティング

| 症状 | 確認ポイント |
|---|---|
| `TCA NOT FOUND`で起動しない | TCA9548Aの配線(外部I2C: SDA=32, SCL=33)、電源 |
| SEN0628が`not found`/`begin NG` | 該当TCAチャンネル(CH1/2/3)の配線、SEN0628のI2Cアドレス(0x33) |
| BMA400が`not found`/`init NG` | TCA CH0の配線、BMA400のI2Cアドレス(0x15)、Seeed_BMA400ライブラリ導入済みか |
| キャリブレ中に壁へぶつかりそうになる | v23で前方ToFによる自動中断を廃止したため、直線区間の長さは運用者側で確保する必要がある。足りない場合は`CAL_PASS_DRIVE_MS`を短くするか、コースを見直す(PARAMETERS.md参照) |
| キャリブレが`NOT CONVERGED`のまま収束しない | `TRIM_LIMIT`張り付きを確認。張り付いていればハード側の左右非対称を疑う |
| 走行中に左右へ流れる | まずBtnBキャリブレを再実行。改善しなければ`AUTO_TRIM_RATE`/`CAL_TRIM_GAIN`(v16で引き上げ済み、未検証)の振動有無を確認 |
| 点群ビューアーが「受信停止」表示のまま | PCのWi-Fi接続先が`M5_POINT_CLOUD`になっているか、UDPポート4210がファイアウォールで塞がれていないか |
| 点群ビューアーの軌跡が実際の動きとズレる | README.mdの「既知の課題・未検証事項」参照(BMA400軸の未実機検証など) |
| 障害物・壁に接触する/避けきれない(v20〜) | 超信地旋回廃止により旋回半径が大きくなっているため。v26で`FWD_CMD`/`FWD_SLOW_CMD`を140/120へ減速し、前方回避判定も120〜180mmへ早めた。まだ接触する場合はLCD/点群ビューアーで検出距離と回避方向を確認する(PARAMETERS.md 1.4/1.5節参照) |
| 前・左・右がすべて赤 | コーナー脱出として設定方向へ2000msカーブバックしてから、四角検知時に固定した90°目標まで残り角度だけ旋回する。バック終了角からさらに90°は回さない |
| 前方極近でバックする | v40以降は3000ms直線後退する。後方センサーがないため、通常走行でも後方空間を確保する |
| motorTrimの適用 | v29以降はBtnBキャリブでNVSへ保存された値だけを、キャリブ時・通常走行とも全量適用する。走行中の自動学習はしない。片輪停止/強旋回時だけは左右の旋回力を揃えるためtrimを適用しない |
| センサー視野の端にある障害物への反応が弱い | v30以降は前方8列すべてを使用し、3基それぞれの左右端2列を2セルから反応する専用判定で補強する。LCD/点群ビューアーで端の障害物に対応する方向が赤へ変わるか確認する |
| 床を障害物として拾う | v31以降は障害物判定を中央4行(row 2〜5)に限定し、床を拾いやすい上下各2行を走行判断から除外する。点群には診断用として全8行が引き続き表示される |
| 四角での周回方向 | `CLOCKWISE=true`なら右へ90°（時計回り）、`false`なら左へ90°（反時計回り）。前方赤でIMU基準90°旋回へ入り、全部赤なら同方向へ2000msカーブバックしてから90°旋回する |
| 瞬間的な前方赤で90°旋回する | v35以降は全点をXY変換し、前方壁と周回外側の側壁が作るL字形状＋異なる2フレーム＋200ms継続で四角確定する。細い障害物・単独壁・短い検知は通常回避になり、その後LCD `RETURN`で元の直進角度へ戻る |
| 後壁に密着した障害物を四角と誤認する | v36以降は前方壁に50mm区画で400mm以上の連続幅を要求する。最大幅300mmの障害物と、その左右に分断して見える後壁はL字コーナーから除外する |
| 幅約1mのコース中央で通路認識されない | v37以降は車幅約30cmから中央時のタイヤ外端クリアランスを片側約35cmと算出し、通路壁認識上限を420mmへ拡大している |
| 半透明プラ板の検知が弱い | v42以降は前方警戒を280mm、側方警戒を320mm、個別セル警戒を280mmへ拡大し、少数有効点の警戒スコアを50へ上げている。ただしToF光を透過する素材は常時検知を保証できない |
| コース中央の障害物で回避方向が定まらない | v43以降はL字でなく左右差が小さい前方赤を`CENTER_L/R`として、時計回りなら右、反時計回りなら左へ固定回避する。通過後は`RETURN`で元方位へ戻る |
| 中央障害物の規定回避側が狭い | v44以降は規定回避側のクリアランスが車幅300mm未満で、反対側に300mm以上ある場合、自動的に反対側へ逃がす |
| 左右表示が通常走行中も常に赤い | v45以降は左右の代表距離を160/250mm、左右8x8点群を130/230mmへ縮小した。前方の半透明板対策用160/280mmは維持する |
| 3秒バック後も前方が赤いのに前進する | v46以降はバック時間終了後も`BACK_HOLD`で停止し、前方赤の解除が300ms連続した場合だけ走行へ復帰する。後方センサーがないためバックの無期限延長はしない |
| 前方表示が障害物通過後も赤のまま残る | v47以降はSEN0628の64セル読取バッファを毎フレーム取得前に全消去する。センサーが一部セルを更新しなかった場合も前回の近距離値を再利用しない |
| バッファ消去後も前方だけ常時赤い | v48以降は消去済み一時バッファへ取得し、成功時だけキャッシュを更新する。前方判定は床側row 4〜5を外したrow 1〜3のみ使用する。左右判定はrow 2〜5のまま |
| LCDが`SENSOR_WAIT`のまま走らない | 3基のうち少なくとも1基が未初期化・測距失敗・620ms超の更新停止。安全のため欠測中は走行しない。LCD/Serial/点群ビューアーでfront/left/rightのどれが更新されていないか確認する |

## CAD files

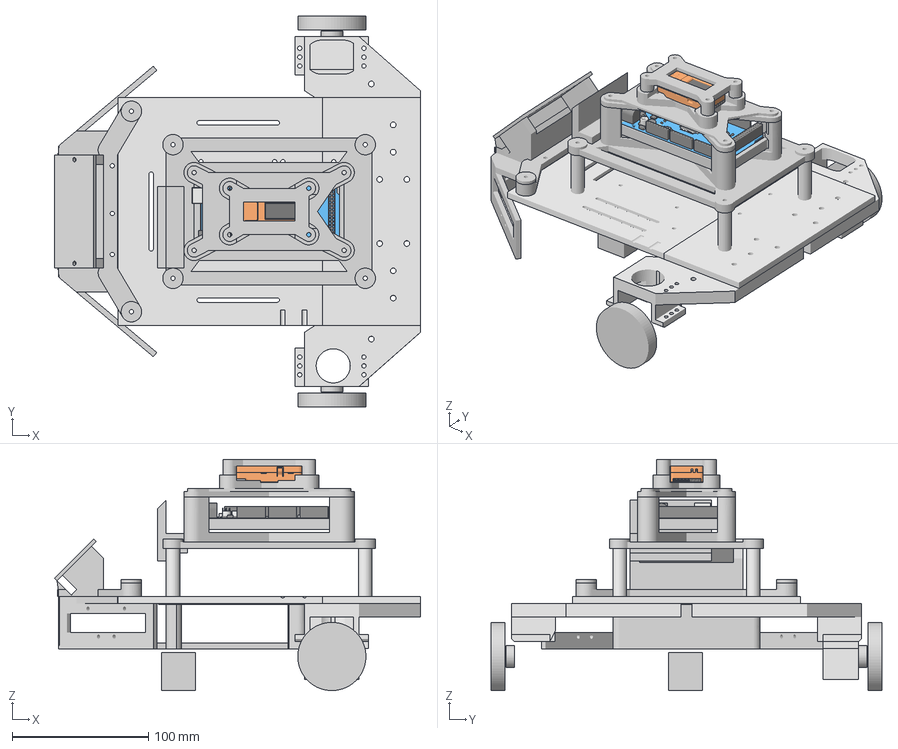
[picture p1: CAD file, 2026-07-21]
robot-parts-all.3mf
268.4 x 286.4 x 169.5 mm
10-pin Header
100nF Capacitor (1)
100nF Capacitor (10)
100nF Capacitor (2)
100nF Capacitor (3)
100nF Capacitor (4)
100nF Capacitor (5)
100nF Capacitor (6)
100nF Capacitor (7)
100nF Capacitor (8)
100nF Capacitor (9)
100nF Capacitor
10k SMD Resistor Network Array (1)
10k SMD Resistor Network Array
16MHz Clock/Crystal
16MHz Resonator
18x2 Header
1M SMD Resistor 2
1M SMD Resistor
1k SMD Resistor Network Array (1) (1)
1k SMD Resistor Network Array (1)
22 Ohm SMD Resistor Network Array (1) (2)
22pF Capacitor 0603 (1)
22pF Capacitor 0603 (2)
22pF Capacitor 0603 (3)
3.3V Voltage Regulator LP2985
47 uF 25VDC Capacitor 1
47 uF 25VDC Capacitor 2
5V Voltage Regulator SOT-223
8-pin Header 1
8-pin Header 2
8-pin Header 3
8-pin Header 4
8-pin Header 5
A1SHB MOSFET
AREF Pins
ATmega16U2
ATmega2560
BRNCG0603MLC-05E Varistor (1)
BRNCG0603MLC-05E Varistor
Barrel Jack 2.1 x 5.5mm
CD1206-S01575 Diode 2
CD1206-S01575 Diode
Capacitor Gray
ICSP Pins
MP2307 Buck Regulator
On LED
PCB
PWM Capacitor
Pin 13 Onboard LED
Polyfuse
RVP Diode
Reset Button
Rx LED
Tx LED
USB-B Connector
ボディ1 (1)
ボディ1 (2)
ボディ1 (3)
ボディ1 (4)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

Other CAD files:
robot-parts-all.stl

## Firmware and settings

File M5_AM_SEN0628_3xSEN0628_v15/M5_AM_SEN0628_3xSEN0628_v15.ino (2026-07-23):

/*
  M5StickC Plus + Arduino Mega + ToF/SEN0628
  SEN0628 corridor follow v8: PIVOT-TURN architecture
  v9: + motor L/R calibration (trim)
  v10: sensor suite unified to 3x SEN0628 8x8, angles 0/+50/-50deg

  現行運用変更:
    - SEN0628の距離閾値は、テスト時の値へ一律40mmを加えた固定値を採用。
    - 左右モータ差はIMUヨー補正とNVSに保存されたmotorTrimだけで補正する。
    - 側方距離はセンサー位置からタイヤ外端までの50mmを差し引き、
      タイヤ外端基準のクリアランスとして回避判定する。
    - 通常はIMU方位を維持して前進し、障害物検知時だけLCD赤判定による
      ピボット回避、前方極近時だけバックを行う。
    - BtnBは停止中の最大速度10秒直進テスト専用。IMUヨードリフトから
      motorTrimを算出し、NVSへ保存する。

  v43: コース中央に置かれた障害物の回避方向を固定。

  v43 changes:
    - 前方赤、L字形状なし、左右スコア差15以内、左右クリアランス差50mm以内を
      CENTER_OBSTACLEと判定。
    - CLOCKWISE=trueなら右、falseなら左へ、既存STEER_MAX_DEG(35度)で
      前進しながら固定回避する。
    - 左右同値時にlastSteerDirへ依存して回避方向が変わる挙動を解消。
    - 中央障害物は90度コーナーTURN/コーナーカーブバックへ入れず、
      通過後はRETURNで回避前の直進方位へ戻す。

  v42: 半透明プラ板の弱い反射と、幅約1mの広いコースに合わせて再調整。

  v42 changes:
    - FWD_CMD 140->155、FWD_SLOW_CMD 120->135。最低指令110は維持。
    - FRONT_SLOW_MM 200->320、FRONT_HARD/WARN 120/180->180/280。
    - SIDE_DANGER/WARN 120/160->200/320。
    - SEN_DANGER/WARN 100/160->160/280。
    - 有効点が少ない弱反射時の警戒スコアを40->50へ引き上げ。
    - 【注意】半透明板はToF光を透過・乱反射するため、実機で欠測状況を確認すること。

  v41: 四角判定時のバック過多で90度旋回後に引っ掛かる問題を調整。

  v41 changes:
    - CORNER_BACK_MSを3000->2000msへ短縮。
    - 前方極近時の通常直線バックFORCE_BACK_MS=3000msは維持。
    - 四角検知時の最終目標ヨーをバック前に固定。カーブバックで回った角度を含めて
      合計90度とし、バック終了角からさらに90度回す過旋回を修正。

  v40: 前方極近時の通常バックも実走可能な3秒へ延長。

  v40 changes:
    - FORCE_BACK_MSを400->3000msへ変更。
    - 通常直線バック、コーナーカーブバックともに3000ms。
    - 【注意】後方センサーなしで3秒後退するため、後方空間の確保が必要。

  v39: コーナー脱出時のカーブバックを最低3秒へ延長。

  v39 changes:
    - CORNER_BACK_MSを700->3000msへ変更。
    - 【v40で変更】前方極近時の通常直線バック時間。
    - 【注意】後方センサーなしで3秒後退するため、後方空間の確保が必要。

  v38: コーナー脱出時のカーブバック距離を延長。

  v38 changes:
    - ALL_RED/四角脱出時のカーブバックを400ms->700msへ延長。
    - 【v40で変更】前方極近時の通常直線バック時間。

  v37: 実コース幅が約1000mmと判明したため通路認識範囲を更新。

  v37 changes:
    - 車幅約300mmの場合、中央時のタイヤ外端〜壁は片側約350mm。
      CORRIDOR_MAX_WALL_MMを260->420へ拡大し、中央走行を通路として認識可能にした。
    - 幾何四角判定の外周側壁探索上限も380->600mmへ拡大。
    - 四角の前方連続壁400mm条件は維持。幅1000mmのコース壁に対し十分小さく、
      最大幅300mmの障害物を除外する境界としても有効。

  v36: 後壁へ密着した最大幅300mmの障害物をL字コーナーと誤認しないよう改善。

  v36 changes:
    - 前方壁候補をy方向50mm区画へ分割し、点の最小〜最大幅ではなく
      「欠落なく連続して埋まった横幅」で評価する。
    - 四角の前方壁には400mm以上の連続幅を要求。
      最大300mmの障害物前面は除外し、障害物の左右に見える後壁も
      中央の欠落によって別々の壁片として扱う。
    - 合成点群で幅約700mmのコース壁は距離70〜300mmの全域で
      400〜600mm連続、幅300mm以下の障害物は400mm未満になることを確認。

  v35: 8x8 ToF x3の点群をXY座標へ変換し、四角を幾何形状で判定。

  v35 changes:
    - 各セルを x=L*cos(theta), y=L*sin(theta) で車体座標へ変換。
    - 前方70〜320mmでxが約25mm幅に揃い、横幅140mm以上に連続する点群を
      「前方を横切る壁」と判定。
    - CLOCKWISE=trueでは左側、falseでは右側をコーナー外周壁とし、
      yが約25mm幅に揃い、前後長120mm以上に連続する点群を「側壁」と判定。
    - 前方壁と側壁の推定交点が側壁範囲内にある場合だけL字形状とする。
    - L字形状+前方赤+異なる2フレーム+200ms継続の全条件で四角確定。
    - L字にならない細い障害物・単独壁・単発点は通常回避のまま。

  v34: 四角の瞬間誤判定防止と、通常障害物回避後の直進方位復帰を追加。

  v34 changes:
    - 前方赤が200ms継続し、異なる前方測距フレームで2回連続した場合だけ
      四角確定とし、90度旋回へ入る。
      単発/短時間の前方赤は通常の連続ステア回避として処理する。
    - 通常回避へ入る直前のtargetYawDegを保存し、障害物消失後280ms保持してから
      保存方位へ戻す。誤差3度以内または2000msで復帰完了。
    - 方位復帰中は通路中央補正と競合させず、LCD reasonをRETURNとする。
    - 90度コーナー旋回後は旋回後ヨーを新しい直進基準とし、旧方位へ戻さない。
    - ALL_REDバックも前方赤200ms継続後にだけ発動する。

  v33: 周回方向を固定設定し、四角検知時の旋回をIMU基準90度へ変更。

  v33 changes:
    - CLOCKWISEパラメータを追加。true=時計回り(右90度)、false=反時計回り(左90度)。
    - 前方赤を四角到達としてDS_CORNER_TURNへ入り、開始ヨーから設定方向へ
      90度変化するまで片輪タンクターンを継続する。
    - 旋回終了許容差5度、タイムアウト3000ms。終了後500msは再トリガを抑制。
    - ALL_RED時は設定方向へカーブバックした後、同じ90度旋回へ接続する。
    - DS_ESCAPE_TURNをDS_CORNER_TURNへ置換するがenum値1は維持。
    - 【要実機確認】CLOCKWISE=trueで右90度、falseで左90度となり、
      LCD reasonがCORNER_R/CORNER_LからRUNへ戻ること。

  v32: 四角/コーナーで「壁検知→旋回→三方向すべて赤」となった際、
       直線バックと停止だけでは車首が壁から外れず脱出できない問題へ対応。

  v32 changes:
    - ALL_RED時は広い側へカーブバックし、続けて同方向へ800msの
      強制片輪タンクターンを行ってから通常判定へ戻る。
    - 未使用だったDS_PIVOTの値1をDS_ESCAPE_TURNとして再利用し、
      DS_BACK=2/DS_CALIBRATING=3の値は維持する。
    - 前方極近だけの通常BACKは従来どおり直線バック。
    - 後方センサーがないため後退時間は400msから延長しない。
    - 【要実機確認】ALL_RED時にBACK_ARC_L/R→ESCAPE_L/Rと遷移すること。

  v31: v30の全セル角度統合後、縦視野端が床を障害物として拾う実走結果へ対応。

  v31 changes:
    - 障害物判定に使う縦方向を中央4行(row 2〜5)へ限定。
      上下各2行(row 0,1,6,7)は床・車体・天井反射を避けるため走行判断から除外。
    - minMm/validCount/nearCount、前方全列、左右端列、192セル角度統合の
      全経路で同じ有効行範囲を使用する。
    - raw 8x8取得とUDP点群配信は全行を維持し、診断表示からは床反射を消さない。
    - 水平方向は全8列・3基統合のまま維持する。
    - 【要実機確認】床だけの状態で赤判定にならず、中央4行へ映る壁・障害物には
      従来どおり反応すること。

  v30: 8x8 ToFの視野エッジで障害物への反応が弱い実走結果へ対応。

  v30 changes:
    - 前方SEN0628の回避判定を中央6列(1〜6)から全8列(0〜7)へ拡張。
      これまで意図的に除外していた左右端列も前方回避へ使う。
    - 3基それぞれの左右端2列(0,1,6,7)を専用集計し、2セル以上が
      SEN_WARN_MM未満なら最低65点、SEN_DANGER_MM未満なら最低90点とする。
    - 端列専用判定を各センサーのスコアへ合成し、中央値へ潰すと消えていた
      細い障害物・センサー視野の継ぎ目を変針判断へ反映する。
    - 点群ビューアーと同じ水平角モデル(60度/8列、列中心7.5度刻み)を走行制御へ導入。
      3基x64点を前方(-32〜+32度)、左(+18〜+80度)、右(-80〜-18度)の
      重なり付きセクターへ統合し、センサー間の約10度重複も回避判断へ使う。
    - 走行方式、速度、motorTrim、NVS、ALL_REDバック条件は変更していない。
    - 【要実機確認】LCD/点群で端に映る障害物に対して該当方向が赤へ変わり、
      接触前に反対側へ変針すること。

  v29: motorTrimの通常走行時適用をキャリブレーションと統一。

  v29 changes:
    - v28で追加した低速時の適用trim±0.12制限を撤回。
    - 通常走行は起動時にNVSから読み込んだmotorTrimを全量そのまま適用する。
    - AUTO_TRIM_ENABLEをfalseにし、走行中の微学習・NVS自動更新を停止。
      motorTrimの更新元はBtnBキャリブレーションと明示的NVSリセットだけに限定する。
    - 片輪停止/強旋回時のtrim無効化は、左右の旋回力を揃えるため維持。

  v28: 実車寸法と実走結果を反映。STL外形は約268x286mmで実測最大幅約300mmと整合。
       中央時の左右斜め測距約350mmを50度で側方投影すると約268mm、
       センサーからタイヤ外端まで50mmを引いた実クリアランスは約218mmとなる。

  v28 changes:
    - OBSTACLE_RED_SCOREを70->60(3/5)へ変更し、回避開始を早めた。
    - CORRIDOR_MAX_WALL_MMを160->260へ変更。中央時約218mmのタイヤ外端
      クリアランスを通路壁として認識できるようにした。
    - TURN_CMD=210を追加し、前方赤時の片輪停止旋回をFWD_SLOW_CMD(120)より強化。
    - 片輪停止旋回にはmotorTrimを適用しない。左右どちらへ旋回する場合も、
      駆動側の片輪へ同じTURN_CMDが届くようにした。
    - 【v29で撤回】低速実走指令での適用trim±0.12制限。
    - 【要実機確認】通常走行時の左弱体化、左右両方向の旋回力、中央時の
      corridorMode認識を確認すること。

  v27: 実走で前・左・右がすべて赤の状態でも避けきれなかったため、
       三方向すべて赤なら前進タンクターンをやめ、即バックへ切り替える。

  v27 changes:
    - frontRed && leftRed && rightRedをALL_REDとして、起動後待機時間に関係なくBACKトリガへ追加。
      直前のバックからクールダウン中も前進へ戻さず、ALL_RED_WAITで停止する。
    - 前方最小距離FRONT_STOP_MM未満の従来BACK条件は維持。
    - 前だけ赤、または前+片側赤の場合は従来どおり空いている側へのタンクターンを維持。
    - 【要実機確認】ALL_RED時にLCD reasonがBACKへ変わり、後退すること。

  v26: キャリブレーション成功後の実走フィードバックを反映。軽量化した車体に対して
       速度下限が高く、前方センサーの回避反映距離も短かったため、キャリブ系は維持したまま
       実走速度と障害物判定距離だけを調整。

  v26 changes:
    - FWD_CMD 155->140、FWD_SLOW_CMD 145->120、MIN_MOVING_CMD 140->110。
      Mega側MIN_EFFECTIVE_CMDも132->100へ下げ、軽量化後の低速域を使えるようにした。
    - FRONT_SLOW_MM 120->200、FRONT_HARD_MM 75->120、FRONT_WARN_MM 100->180。
      前方障害物を従来より遠い位置から減速・回避へ反映する。
    - SEN_DANGER_MM 60->100、SEN_WARN_MM 80->160。8x8個別セルで捉えた
      細い障害物も、接触直前ではなく余裕のある距離からスコアへ反映する。
    - 3基のうち1基でも未初期化・読み取り失敗・SENSOR_STALE_MS超過なら
      「安全(スコア0)」として走らず、reason:SENSOR_WAITで停止するフェイルセーフを追加。
    - センサーポーリング順、キャリブレーション、motorTrimは変更していない。
    - 【要実機確認】最低出力100で連続走行できるか、約120〜180mmからの前方回避で
      タイヤ外端が引っかからなくなったかを確認すること。

  v24: キャリブ結果(LCD Drift表示)と実機の見た目の変針量が大きく食い違うという報告
       (表示-2.9degに対し実際は右へ5〜60度)への対応。yawDeg積分がdt>=0.2sの回を
       丸ごと捨てていたバグを修正、各パスの生ドリフト値もLCD/Serialに表示するよう追加。

  v24 changes:
    - updateIMU(): 旧実装は dt>=0.2s の回をヨー積分から完全に除外していた
      (streamPointCloud()等でループが一瞬詰まりdtが伸びると、その間の実回転が
      yawDegに一切反映されない)。dtを捨てず、上限0.5sでクランプしてから必ず積分するよう修正。
    - runStraightCalibration(): ラウンド確定時に中央値だけでなく、各パスの生ドリフト値を
      Serial(常時)とLCD(小文字表示)に出力するようにした。中央値に隠れた外れ値パスの
      有無を次回テストで直接確認できる。
    - 【要実機再確認】(1)がユーザー報告の食い違いの原因だったかは未確認。次回のBtnB
      キャリブレでLCD/Serialの各パス値と実際の変針量を突き合わせて検証すること。

  v23: ユーザーフィードバックによる調整4件。(1) v21のWiFi STA接続を撤回しSoftAP方式に戻した
       (学校WiFi等、認証情報を書き込むのが望ましくない環境を考慮)。(2) 走行速度をさらに減速
       (FWD_CMD 180->165, FWD_SLOW_CMD 165->155)。(3) キャリブレーション中の前方ToF
       スペースチェック(CAL_ABORT_FRONT_MM)を廃止し、パスは常にCAL_PASS_DRIVE_MSいっぱいまで走る。
       (4) モーター個体差を最大2倍と仮定し、TRIM_LIMITを2倍を補正しきれる値(0.25->0.34)へ
       引き上げ、そこまで自動収束できるようCAL_MAX_ROUNDSも拡大(5->12)。

  v23 changes:
    - setup()を元のWiFi.mode(WIFI_AP)+WiFi.softAP()のみに戻した。wifi_secrets.h/
      wifi_secrets.h.exampleは削除、.gitignoreのwifi_secrets.h行も削除。
    - streamPointCloud()のbeginPacket先を固定192.168.4.255に戻し、flagsのWiFiクライアント
      判定もWiFi.softAPgetStationNum()ベースに戻した(wifiLinkUp()/pointCloudBroadcastIp/
      wifiStationConnected/STATION_WIFI_WIFI_STA_CONNECT_TIMEOUT_MSは削除)。
    - runOneCalPass()からreadOneSEN(0)呼び出しとCAL_ABORT_FRONT_MMによる早期中断を削除。
      戻り値CAL_PASS_NO_SPACEは(ranMs不足という理論上の保険としてのみ)コード上残存。
    - TRIM_LIMIT: 実効左右比(1+trim)/(1-trim)が2倍に達するよう逆算しT=1/3、余裕を見て0.34へ
      (実機で旧上限0.25に張り付いたままdrift -4.7degが解消しないことを確認済み)。
      CAL_MAX_ROUNDSも5->12に拡大し、0からこの上限まで自動収束できる余地を確保。
    - 【未検証】(2)(3)(4)とも実機での効果確認はまだ行っていない。

  v22: v20で超信地旋回を全廃止した後、「前方に壁が来た時に連続ステアだけでは曲がりきれない」
       懸念(ユーザー指摘)に対応。frontRed時のみ片輪を止める急旋回(タンクターン)を追加。

  v22 changes:
    - frontScoreがOBSTACLE_RED_SCORE以上(frontRed)の場合、通常の連続ステア(2)より優先して
      片輪を0、もう片輪をFWD_SLOW_CMDにするタンクターンを実行する(reason: TURN_L/TURN_R、
      両側危険ならESCAPE_L/ESCAPE_R)。逆転はしないため「常に前進」の方針とは矛盾しない。
    - HEADING_CORR_LIMIT頭打ちの継続ステア(v20)は側方の危険度が高いだけの場合(frontは
      無事)には引き続き使う。前方が実際に危険域に入った場合のみタンクターンへ切り替わる。
    - 【未検証】実機での効き確認はまだ行っていない。

  (v21でWiFi STA接続方式を試したが、学校WiFi等の環境考慮のため撤回しSoftAP方式に戻した)

  v20: 超信地旋回(PIVOT)を全廃止。常に前進しながら、危険度・クリアランス差に応じて
       目標ヨーを連続的に「広い側/安全な側」へバイアスする方式(差動ステアのみ)に変更。

  v20 changes:
    - DS_PIVOT状態・startPivot()・PIVOT_ALIGN_PIVOT_COURSE_RETURN
      CORNER_CONTINUE_WINDOW_MS等のピボット専用ロジック/定数/変数を全削除。
    - 前方回避・側方姿勢直しの2種類のピボットトリガーを、1つの連続ステア計算に統合
      (STEER_MAX_DEG/STEER_URGENCY_MIN)。危険度(0-100スコア)に比例してtargetYawDegを
      その場でバイアスし、実際の差動はheadingCorrection()(±HEADING_CORR_LIMIT)がそのまま担う。
    - DS_BACK(前方極近の緊急バック)は維持。バック後はピボットせずそのままDS_FORWARDへ戻り、
      連続ステアに委ねる。
    - 差動ステアは超信地旋回よりも実効的な旋回半径がずっと大きいため、反応・回避の余裕を
      確保する目的でFWD_CMD(215->180)/FWD_SLOW_CMD(195->165)を減速。
    - 【未検証】この変更は静的コードレビューのみで実機での回避挙動確認はまだ行っていない。
      特に急な障害物・直角コーナーでの回避可否は要実地確認(旧ピボット方式より
      その場での方向転換能力が大幅に落ちているため、狭いコースでは壁に接触するリスクがある)。

  v19: TCA CH0/BMA400と並行して、キャリブレーション(BtnB)の進行状況を
       UDP点群フレーム経由でPC側点群ビューアーへリアルタイム配信するように変更。

  v19 changes:
    - dstateにDS_CALIBRATING(3)を追加。runStraightCalibration()/runOneCalPass()実行中は
      calStreamRound/calStreamPass/calStreamDriftDegを更新しつつstreamPointCloud()を呼ぶ。
    - PointCloudFrameにtrimMilli/calRound/calPass/calDriftCdegを追加(protocol version 4)。
    - PC側point_cloud_viewer.pyはCALIBRATIONパネルでラウンド/パス/ドリフト/トリムを表示する。

  v18: 手動キャリブレ(BtnB直進テスト)を強化。1回10秒の単発測定から、
       短いパスを複数回走って中央値を取る方式+収束するまでの自動ラウンド継続に変更。

  v18 changes:
    - CAL_DRIVE_MS(10秒)を CAL_PASSES_PER_ROUND(3)分割し、1パス約3.3秒に短縮。
      1ラウンドの合計走行距離は旧来の単発10秒とほぼ同じに保ちつつ、3回分のdriftNormを
      中央値で集約するため単発測定のノイズ・外れ値に強くなった。
    - CAL_OK_DEG未満に収束するまで、最大CAL_MAX_ROUNDS(5)ラウンドまで自動継続。
      ラウンド間はBtnBの再操作なしで自動進行はしない(後方無センサのため、
      ロボットを開始位置へ戻す必要がある。LCDでBtnB:継続/BtnA:中止を案内する)。
    - パス中にCAL_ABORT_FRONT_MM(前方近接=コース不足)で止まった場合と、
      BtnA押下による明示的な中止を区別。前者はそのラウンドを打ち切って
      それまでに取れた有効パスだけで中央値を計算(0件なら「CAL FAILED」表示)、
      後者はキャリブレ全体を即座に中止する(ユーザーの明示操作を尊重)。
    - 【未検証】このロジックは静的コードレビューのみで実機での収束確認はまだ行っていない。

  v17: TCA CH0(予約チャンネル)にBMA400(Grove)を追加。点群ビューアーの
       デッドレコニング用に、M5内蔵IMUと並行して加速度をUDP配信する。

  v17 changes:
    - 【実機仕様】BMA400モジュールはコネクタが車体後ろ向きに取付(2026-07-22ユーザー確認)。
      Seeed公式データシート図の座標系(Z=チップ面から手前/垂直上, Y=コネクタと反対方向,
      X=Y×Zの右手系)と照合すると、水平・チップ面上向き取付の前提で
      Y軸=車体前方、X軸=車体右方向に一致し、符号反転や軸入替は不要と判断した
      (Web上のSeeed製品ページの軸図から導出。実機での重力方向テストは未実施)。
    - initBMA400()/readBMA400()を追加。TCA CH0経由、50ms間隔でポーリング。
    - PointCloudFrameにbmaAccelX/Y/ZmilliGを追加(protocol version 3)。
      M5内蔵IMUのaccelXmilliG等と同じmilli-g単位で、両方をPC側で比較・ブレンドできるようにした。
    - BMA400未接続/未初期化でも既存動作に影響しないようフォールバック
      (bmaOK=falseなら該当フィールドは0、flagsのBMA400ビットも立てない)。

  v16: 周回コーナー旋回対応、kick瞬間反転バグ修正(Mega側)、BACK_COOLDOWN無効化バグ修正、
       前方回避方向選択のクリアランス化、corridorMode優先度見直し、各種閾値調整

  v16 changes:
    - 【実測データ】SEN0628の実視野角はDFRobot公称60°(3.5m測距、20-200mm域で
      ±11-12mm精度、最大60Hz)。0/+50/-50degの3基構成だと隣接センサ間で約10度の
      重なりがあり、-80度〜+80度の範囲に角度的な死角はないことを確認した
      (Web検索で確認。実機のFOVそのものは未実測)。
    - 【実測データ】ロボット車体は前方が1〜2度高くなる姿勢で静止する(センサー自体は
      車体に対して水平マウント)。この傾きぶん、全センサーのビームは実際の水平面より
      わずかに上を向く。近距離(数百mm以内)では影響は小さいが、長い直線区間の遠方で
      低い壁を飛び越えて「前方クリア」と誤判定する可能性は理論上ある。センサー高さ・
      壁高さの実測値がないため数値的な補正は入れていない(要注意点として記録のみ)。
    - コーナー(90度)旋回に対応。前方回避ピボットが上限角/タイムアウトで終了(=前方が
      まだ開いていない)した場合、courseReturnActiveで元の(=今避けた壁の)方位に
      戻ろうとするのをやめ、新しいヨーを直進基準として確定するよう変更。
      同時に、同方向への継続旋回(PIVOT_MAX_DEG_CORNER=70度)を追加。
    - 前方回避ピボットの方向選択に、側方クリアランス(leftClear/rightClear)の差が
      大きい場合はクリアランスが広い側を優先する分岐を追加(従来はred/not-redの
      2値と交互選択のみだった)。
    - corridorModeに連続ミス回数によるヒステリシスを追加(瞬間的な障害物検知での
      フリッカーを防止)。また、壁を再検知できたらcourseReturnActiveより
      corridorModeの壁基準中央維持を優先するよう変更(ヨードリフトの影響緩和)。
    - Mega側 AM_HighTorqueAntiStall_..._v4_for_x3.ino: kick機構(発進補助)が
      符号反転のたびに瞬間フルパワー反転を起こすバグを修正(v2参照)。
    - M5側 BACK_COOLDOWN_MSが論理式の冗長ORで無効化されていたバグを修正。
    - POLL_SEQを前方偏重(4:2:2)から均等(1:1:1)へ。側方センサ(通路追従・
      コーナー方向判断の主データ)の鮮度を優先。
    - 前方危険判定の中央列範囲を4列->6列に拡張(中央から外れた細い障害物対策)。
    - 低validCount時の警戒スコアを18->40に引き上げ(減速閾値に届くように)。
    - SIDE_ALIGN_DELAY_MSを1000->400msに短縮(前方回避クールダウン300msとの
      非対称で側方姿勢直しが後回しになっていたのを緩和)。
    - 左右モーター補正をmotorTrimに一本化。
      AUTO_TRIM_RATEを5倍に増加(収束が遅すぎたため)。
    - 前進速度を2値切替から frontScore/側方scoreに応じた連続減速に変更。
    - CORRIDOR_DIFF_DEADBAND_MMを50->30mmに縮小(中央維持精度向上)。
    - 未使用関数 senForwardMm/senForwardMinMm を削除。
    - 【未検証】上記は静的なコードレビューに基づく修正であり、実機での動作確認は
      行っていない。特にCAL_TRIM_GAIN/AUTO_TRIM_RATE/PIVOT_MAX_DEG_CORNER/
      各種閾値の具体的な数値は実走行での再調整が前提。

  v15: 接触保険(IMU衝撃BACK)を削除、LCD表示抜け修正、キャリブ即中断修正

  v15 changes:
    - 接触保険(IMU加速度によるimpactValid BACKトリガ)を完全削除。
      BACKは前方センサ実測の極近(tofRealClose)のみで発動する。
    - 加速度由来の診断値(lastImpactG/accelWarn/連続カウント)は
      TEST_MODE時のみ計算・表示するように変更(実走行には一切影響しない)。
    - LCD表示に「BACK中なのにRUN表示のまま」という抜けがあった原因を特定:
      FORCE_BACK_MS(240ms) < LCD_UPDATE_PERIOD_MS(250ms) のため、
      BACK状態が丸ごと1回も描画されずに終わることがあった。
      -> LCD_UPDATE_PERIOD_MSを80msに短縮し、さらに状態(dstate)が
      変化した瞬間は更新間隔を無視して即座に再描画するように変更。
    - キャリブ走行(個体差テスト)がすぐ中断される問題を修正:
      CAL_ABORT_FRONT_MMがTEST_MODEの極小閾値(60mm)に連動していたため、
      直進テスト自体が数cmの近接ですぐアボートしていた。
      TEST_MODEから切り離し、キャリブ専用の固定値(150mm)に変更。

  v14: 距離センサが何も検知していないのにBACKする問題を修正

  v14 changes:
    - BACKのトリガは「前方センサ実測の極近」か「IMU衝撃検知(impactValid)」の
      いずれかだが、後者は距離センサと完全に無関係(加速度のみ)。
      IMPACT_G_THRESH=0.80という単発サンプルの閾値超えだけで発動していたため、
      走行中の振動・モータのキック・机上の小さな段差等の単発ノイズでも
      「センサは何も見ていないのにBACK」が起こり得た。
      -> 加速度が閾値を連続IMPACT_CONSECUTIVE_REQUIRED回以上続けて超えた場合のみ
      impactLikeをtrueにするよう変更(単発スパイクの除外)。
      IMPACT_G_THRESHも0.80->1.00に引き上げ、二重に安全側へ。

  v13: RUN表示中に後進して見えるバグを修正

  v13 changes:
    - ピボット旋回終了→FORWARD(RUN表示)へ切り替わる瞬間、smoothCmdLeft/Right
      がピボット時の値(片輪が負=逆転)を引きずったまま前進用のゆるいslew
      (CMD_SLEW_PER_SEND=42/回)に渡っていたため、LCDが既に"RUN"を表示していても
      実際の指令は数フレーム(~100〜160ms)片輪が負のまま=後進方向に見える、
      という状態表示と実指令の不整合があった。
      -> ピボット終了時にsmoothCmdLeft/Rightを0にリセットしてから
      FORWARDのランプを開始するように修正。

  v12: TEST MODE (卓上ベンチテスト用の閾値切替)

  v11: threshold retune for small-scale course + faster/visible init

  v11 changes:
    - 実コースの壁間隔は片側10〜50cm程度しかないと判明。
      v10までの閾値(BODY_*_MARGIN他)は倍以上大きい前提だったため、
      常に「危険」判定になり曲がりすぎ/止まりすぎていた。
      -> FRONT/SIDE/SEN/CORRIDOR系の閾値を全て実測スケールに合わせて縮小。
      -> BODY_*_MARGIN/EXTRA_SAFETY方式(加算式)をやめ、直接値で明示。
    - チャンネル配置を実機確認: CH0=BM(未使用/予約), CH1=front(中央),
      CH2=left(ひだり), CH3=right(右)。既存の SEN_CH={1,2,3} 割当は
      この実機配置と一致していたため変更なし(確認のみ)。
    - 起動シーケンスを高速化: 起動前待機 500->150ms、
      センサ初期化後の待機 60->20ms、各センサの初期化進捗をLCDに表示
      (今何番目のセンサを初期化中か分かるようにし、フリーズと区別できるように)。

  v10 changes (sensor hardware change):
    - VL53L0X(単点ToF x3)を完全撤去。前方/左右とも SEN0628 8x8 に統一。
    - マウント角度: idx0=front(0deg), idx1=left(+50deg), idx2=right(-50deg)
      (角度は body forward axis からの水平角。上向きチルトは廃止)
    - 各センサの中心4セル平均距離(centerMm)を、マウント角度で
      前方成分(*cos)・側方成分(*sin)に幾何分解して使用する。
        idx0(0deg):  forward = center,           side = 0
        idx1(+50):   forward = center*cos50,     side  = center*sin50 (左壁距離)
        idx2(-50):   forward = center*cos50,     side  = center*sin50 (右壁距離)
      前方の"real close"判定は idx0 の最小値(minMm)ベースで従来より保守的に判定。
    - 通路モードの leftClear/rightClear は idx1/idx2 の側方成分から算出。
      (旧: 単点ToFとSEN中央の融合 -> 新: 単一8x8の幾何投影)
    - POLL_SEQは前方(idx0)を安全上重要なので多めにポーリング。

  v9 changes:
    - モータ個体差トリム(motorTrim)を追加。M5側で左右指令を
      (1-trim)/(1+trim) 倍してから送信。trim>0 = 右を強め左を弱める。
    - 直進キャリブモードは現行運用変更で最大速度10秒へ更新。
    - 走行中(FWD直進安定時のみ)恒常的なヘディング補正量からトリムを微学習。
    - トリムはNVSに保存し、再起動後も保持。

  v8 changes (turns didn't work / BACK spam / stall):
    - 差動アーク(150:245等)ではこの車体は曲がらない(スキッドステア+高負荷)。
      -> 旋回は全て「正転逆転の超信地旋回」に統一。IMUの旋回角で終了判定。
    - 前進は常に高デューティ固定(215)。低デューティ指令を廃止しストール排除。
    - BACKのトリガから SEN0628 を完全撤去。前方ToF実測の極近 or 衝突検知のみ。
      (BACK頻発の残存原因は上向き8x8が通路壁を拾い続けることだったため)
    - 通路中央維持は「目標ヨーの微調整」+「片側極近時の小角度ピボット」で実現。
    - 状態機械: FORWARD / PIVOT / BACK の3状態。

  Goal:
    - smoother motor behavior
    - more sensitive obstacle avoidance
    - account for robot body size / clearance
    - no distance estimation
    - when a wall/obstacle appears in front, turn left early
    - if front is very close, stop
    - BtnA: IMU zero -> start
    - BtnB: 最大速度10秒の直進補正テスト(停止中のみ)

  Sensor layout (v10/v11, 実機確認済み。v17でCH0にBMA400を追加):
    TCA CH0: BMA400 (Grove, I2C 0x15) - コネクタは車体後ろ向き
    TCA CH1: SEN0628 front  (0 deg, 中央)
    TCA CH2: SEN0628 left   (+50 deg, ひだり)
    TCA CH3: SEN0628 right  (-50 deg, 右)

  UART:
    M5 GPIO26 TX -> AM D19 RX1
    AM D18 TX1 -> level shifter/divider -> M5 GPIO36 RX
    GND common
*/

#include <M5StickCPlus.h>
#include <Wire.h>
#include <Preferences.h>
#include <WiFi.h>
#include <WiFiUdp.h>
#include "DFRobot_MatrixLidar.h"
#include <BMA400.h>  // v17: TCA CH0のBMA400(Grove)。グローバルインスタンス bma400 はライブラリ側で定義済み

// ===============================
// Pin / bus
// ===============================
#define EXT_I2C_SDA 32
#define EXT_I2C_SCL 33

#define BODY_I2C_SDA 21
#define BODY_I2C_SCL 22
// If builtin IMU is dead, try:
// #define BODY_I2C_SDA 0
// #define BODY_I2C_SCL 26

#define AM_UART_RX 36
#define AM_UART_TX 26

HardwareSerial AMSerial(2);
const uint32_t AM_UART_BAUD = 115200;

// ===============================
// TCA / sensors
// ===============================
const uint8_t TCA_ADDR = 0x70;

// v10: 3x SEN0628 8x8, idx0=front(0deg) idx1=left(+50deg) idx2=right(-50deg)
const uint8_t SEN_COUNT = 3;
const uint8_t SEN_CH[SEN_COUNT] = {1, 2, 3};
const float SEN_ANGLE_DEG[SEN_COUNT] = {0.0f, 50.0f, -50.0f};
const uint8_t SEN0628_ADDR = 0x33;

DFRobot_MatrixLidar_I2C senFront(SEN0628_ADDR);
DFRobot_MatrixLidar_I2C senLeft(SEN0628_ADDR);
DFRobot_MatrixLidar_I2C senRight(SEN0628_ADDR);
DFRobot_MatrixLidar_I2C *senDev[SEN_COUNT] = {&senFront, &senLeft, &senRight};
bool senOK[SEN_COUNT] = {false, false, false};

// マウント角度から前方/側方への幾何投影係数(setup()で算出)。
float senCosAbs[SEN_COUNT] = {1.0f, 1.0f, 1.0f};
float senSinAbs[SEN_COUNT] = {0.0f, 0.0f, 0.0f};

struct SenCache {
  bool ok = false;
  int minMm = -1;
  int centerMm = -1;
  int validCount = 0;
  int nearCountDanger = 0;
  int nearCountWarn = 0;
  float captureYawDeg = 0.0f;
  unsigned long updatedMs = 0;
  uint16_t raw[64];
};

SenCache cachedSen[SEN_COUNT];

// v10: 前方(idx0)を安全上重要なので多めにポーリング。左右(idx1,2)は交互。
// v16: このコースは常に両側壁があり、側方センサは通路追従(壁基準の中央維持・
// コーナー旋回方向判断)の主要データでもあるため、前方偏重(4:2:2)から均等(1:1:1)に
// 変更。前方の安全マージンはFRONT_STOP_MM等の即時トリガで別途担保されており、
// ポーリング比率を下げても即時反応性は変わらない。
// (実センサのI2C読み取り所要時間は未計測。安全マージンに余裕が無いと分かれば
//  前方寄りの比率に戻すこと)
const uint8_t POLL_SEQ[] = {0, 1, 2, 0, 1, 2};
const uint8_t POLL_SEQ_LEN = sizeof(POLL_SEQ) / sizeof(POLL_SEQ[0]);
uint8_t pollSeqIndex = 0;

// ===============================
// BMA400 (Grove, TCA CH0) - v17
// ===============================
// コネクタが車体後ろ向きに実装されている(2026-07-22ユーザー確認)。Seeed製品ページの
// センサー座標系シルク図(Z=チップ面から手前=垂直上、Y=コネクタと反対方向、
// X=Y×Zの右手系)と照合すると、水平・チップ面上向き取付の前提でX軸=車体右、
// Y軸=車体前方に一致する。よってgetAcceleration()の生値(mg)はそのまま
// 「右方向/前方向」として使える(符号反転・軸入替は不要と判断)。
// ただし実機での重力方向テスト(静止時Z≒+1000mg等)による裏取りはまだ行っていない。
const uint8_t BMA400_TCA_CH = 0;
const unsigned long BMA400_READ_PERIOD_MS = 50;  // 点群配信(50ms)と同程度で十分

bool bmaOK = false;
float bmaAccelXG = 0.0f;  // 車体右方向, g単位(getAcceleration()のmgを1000で除算)
float bmaAccelYG = 0.0f;  // 車体前方向, g単位
float bmaAccelZG = 0.0f;
unsigned long bmaUpdatedMs = 0;
unsigned long lastBmaReadMs = 0;

void initBMA400() {
  useExternalI2C();

  M5.Lcd.fillScreen(BLACK);
  M5.Lcd.setCursor(0, 6);
  M5.Lcd.setTextSize(2);
  M5.Lcd.setTextColor(WHITE, BLACK);
  M5.Lcd.println("INIT BMA400");

  if (!tcaSelect(BMA400_TCA_CH)) {
    tcaDisableAll();
    M5.Lcd.setTextColor(RED, BLACK);
    M5.Lcd.println("TCA NG");
    delay(300);
    return;
  }

  if (!i2cExists(BMA400_ADDRESS)) {
    Serial.println("BMA400 not found on CH0");
    M5.Lcd.setTextColor(RED, BLACK);
    M5.Lcd.println("not found");
    tcaDisableAll();
    delay(300);
    return;
  }

  bma400.initialize();
  bmaOK = bma400.isConnection();
  tcaDisableAll();

  M5.Lcd.setTextColor(bmaOK ? GREEN : RED, BLACK);
  M5.Lcd.println(bmaOK ? "OK" : "init NG");
  delay(300);
}
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
void loop() {
  M5.update();
  readAMTelemetry();

  // BtnA+BtnB同時押し: drive名前空間のNVSを初期化する。
  // 押しっぱなしで繰り返しclear()しないよう、両ボタンを離すまでラッチする。
  bool nvsResetCombo = M5.BtnA.isPressed() && M5.BtnB.isPressed();
  if (nvsResetCombo) {
    if (!nvsResetComboLatched) {
      nvsResetComboLatched = true;
      resetDriveNVS();
    }
    return;
  }
  if (nvsResetComboLatched) {
    if (!M5.BtnA.isPressed() && !M5.BtnB.isPressed()) {
      nvsResetComboLatched = false;
    }
    return;
  }

  if (M5.BtnA.wasPressed()) {
    zeroIMUAndStart();
  }

  // BtnBの割り当ては、停止中の最大速度10秒トリムテストのみ。
  if (!driveEnabled && M5.BtnB.wasPressed()) {
    runStraightCalibration();
  }

  // v9: 自動学習分の定期保存(変化があった時のみ書き込み)
  if (millis() - lastTrimSaveMs > TRIM_SAVE_PERIOD_MS) {
    lastTrimSaveMs = millis();
    if (fabs(motorTrim - savedTrim) > 0.01f) saveTrim();
  }

  float ax = 0, ay = 0, az = 0;
  float gx = 0, gy = 0, gz = 0;

  readBuiltinIMU(ax, ay, az, gx, gy, gz);
  updateIMU(ax, ay, az, gx, gy, gz);

  pollOneSensor();
  readBMA400();

  computeAndDrive();
  drawStatus();
  debugSerial();
  streamPointCloud();

  delay(0);
}

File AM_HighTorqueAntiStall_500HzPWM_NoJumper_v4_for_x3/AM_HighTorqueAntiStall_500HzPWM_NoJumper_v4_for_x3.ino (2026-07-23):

/*
  Arduino Mega + L298N MotorOnly
  High-torque anti-stall 500Hz PWM version for no ENA/ENB jumper removal.

  Fixes:
    - previous kick could repeat too often and feel jerky
    - low PWM command stalled under load
    - target changes are smoothed
    - kick is short and has cooldown

  v2 (paired with M5 v16):
    - applyKickToOutput() no longer overrides direction on a sign-change kick
      while actual is still ramping through zero. Previously a sign change
      (even a tiny one, e.g. +4 -> -4 from the M5-side slew) instantly forced
      actual's output to full KICK_CMD in the NEW direction regardless of
      actual's current (old-direction) magnitude, defeating approachCmd's
      "always pass through zero" reversal safety. Now the kick only applies
      once actual's own sign already matches kickSign.

  Wiring:
    L298N IN1 -> AM D22 / PA0
    L298N IN2 -> AM D23 / PA1
    L298N IN3 -> AM D24 / PA2
    L298N IN4 -> AM D25 / PA3

    AM D18 TX1 -> level shifter/divider -> M5 GPIO36 RX
    AM D19 RX1 <- M5 GPIO26 TX
    GND common
*/

#include <Arduino.h>

// D22-D25 are PORTA bit0-bit3 on Arduino Mega.
const uint8_t MOTOR_MASK = 0x0F;

const bool INVERT_LEFT_MOTOR  = false;
const bool INVERT_RIGHT_MOTOR = false;
const bool SWAP_LEFT_RIGHT    = false;

// 500Hz PWM, close to common Arduino PWM frequency.
const uint16_t PWM_PERIOD_US = 2000;

// Smooth ramp.
const unsigned long RAMP_PERIOD_MS = 2;
const int RAMP_UP_STEP = 20;
const int RAMP_DOWN_STEP = 22;
const int REVERSE_ZERO_STEP = 36;

// v26: 車体軽量化により低速でも走行可能になったため、実走速度の下限を下げる。
// 発進時はKICK_CMDが別途働くので、ここは連続走行を維持できる最低値として調整する。
const int MIN_EFFECTIVE_CMD = 100;

// Short kick only when starting from rest, not on every target update.
const int KICK_CMD = 225;
const unsigned long KICK_MS = 150;
const unsigned long KICK_COOLDOWN_MS = 180;

const unsigned long COMMAND_TIMEOUT_MS = 720;
const unsigned long TELEMETRY_PERIOD_MS = 35;
const unsigned long BRAKE_PULSE_MS = 30;

const bool DEBUG_USB = false;

int targetLeft = 0;
int targetRight = 0;
int actualLeft = 0;
int actualRight = 0;

unsigned long kickLeftUntilMs = 0;
unsigned long kickRightUntilMs = 0;
unsigned long lastKickLeftMs = 0;
unsigned long lastKickRightMs = 0;
int kickLeftSign = 0;
int kickRightSign = 0;

unsigned long lastCommandMs = 0;
unsigned long lastTelemetryMs = 0;
unsigned long lastRampMs = 0;
unsigned long brakeUntilMs = 0;

char m5Line[80];
uint8_t m5LineLen = 0;

char usbLine[80];
uint8_t usbLineLen = 0;

int clampRaw(int v) {
  if (v > 255) return 255;
  if (v < -255) return -255;
  return v;
}

int signOf(int v) {
  if (v > 0) return 1;
  if (v < 0) return -1;
  return 0;
}

int applyMinimumEffective(int v) {
  v = clampRaw(v);
  if (v == 0) return 0;

  int s = signOf(v);
  int mag = abs(v);

  if (mag < MIN_EFFECTIVE_CMD) {
    mag = MIN_EFFECTIVE_CMD;
  }

  return s * mag;
}

void maybeStartKick(int oldTarget, int newTarget, int actual,
                    unsigned long &kickUntil, unsigned long &lastKick, int &kickSign) {
  if (newTarget == 0) return;

  unsigned long now = millis();
  int oldS = signOf(oldTarget);
  int newS = signOf(newTarget);

  bool startingFromRest = oldS == 0 && abs(actual) < MIN_EFFECTIVE_CMD;
  bool signChanged = oldS != 0 && newS != 0 && oldS != newS;

  if ((startingFromRest || signChanged) && (now - lastKick > KICK_COOLDOWN_MS)) {
    kickUntil = now + KICK_MS;
    lastKick = now;
    kickSign = newS;
  }
}

int approachCmd(int cur, int tgt) {
  cur = clampRaw(cur);
  tgt = applyMinimumEffective(tgt);

  if (cur == tgt) return cur;

  // No instant reverse. Always pass through zero.
  if ((cur > 0 && tgt < 0) || (cur < 0 && tgt > 0)) {
    if (cur > 0) return max(0, cur - REVERSE_ZERO_STEP);
    if (cur < 0) return min(0, cur + REVERSE_ZERO_STEP);
  }

  int step = (abs(tgt) > abs(cur)) ? RAMP_UP_STEP : RAMP_DOWN_STEP;

  if (cur < tgt) {
    cur += step;
    if (cur > tgt) cur = tgt;
  } else {
    cur -= step;
    if (cur < tgt) cur = tgt;
  }

  return clampRaw(cur);
}

int applyKickToOutput(int actual, unsigned long kickUntil, int kickSign) {
  if (actual == 0) return 0;

  // v2: キックはactualの符号が既にkickSignと一致している間だけ効かせる。
  // 符号反転の直後はactualがまだ旧符号のまま0へ向けてランプ中(approachCmdの
  // REVERSE_ZERO_STEPによる「必ず0を経由する」処理の途中)であり、そこでkickSignを
  // 無条件適用すると瞬間フルパワーの逆転になってしまう(approachCmdの安全策を無効化する)。
  // actualが実際に新符号側へ入ってから初めてキックを乗せることで、
  // 0経由の滑らかな反転を保ったまま「発進/転換直後の粘り抜け」だけ助ける。
  int actualSign = (actual > 0) ? 1 : -1;
  if (millis() < kickUntil && kickSign != 0 && actualSign == kickSign) {
    int mag = max(abs(actual), KICK_CMD);
    return kickSign * constrain(mag, 0, 255);
  }

  return actual;
}

void writeMotorBits(uint8_t bits) {
  PORTA = (PORTA & ~MOTOR_MASK) | (bits & MOTOR_MASK);
}

void applyMotorOutputs() {
  int left = applyKickToOutput(actualLeft, kickLeftUntilMs, kickLeftSign);
  int right = applyKickToOutput(actualRight, kickRightUntilMs, kickRightSign);

  if (SWAP_LEFT_RIGHT) {
    int t = left;
    left = right;
    right = t;
  }

  if (INVERT_LEFT_MOTOR) left = -left;
  if (INVERT_RIGHT_MOTOR) right = -right;

  left = clampRaw(left);
  right = clampRaw(right);

  bool brakeNow = millis() < brakeUntilMs;
  if (brakeNow) {
    writeMotorBits(MOTOR_MASK);
    return;
  }

  uint16_t phase = micros() % PWM_PERIOD_US;
  uint16_t leftOn  = (uint32_t)abs(left)  * PWM_PERIOD_US / 255;
  uint16_t rightOn = (uint32_t)abs(right) * PWM_PERIOD_US / 255;

  bool onL = (abs(left) > 0) && (phase < leftOn);
  bool onR = (abs(right) > 0) && (phase < rightOn);

  uint8_t out = 0;

  if (onL) {
    if (left > 0) out |= _BV(0);
    else          out |= _BV(1);
  }

  if (onR) {
    if (right > 0) out |= _BV(2);
    else           out |= _BV(3);
  }

  writeMotorBits(out);
}

void updateRamp() {
  unsigned long now = millis();
  if (now - lastRampMs < RAMP_PERIOD_MS) return;
  lastRampMs = now;

  actualLeft = approachCmd(actualLeft, targetLeft);
  actualRight = approachCmd(actualRight, targetRight);
}

void setTarget(int l, int r) {
  l = clampRaw(l);
  r = clampRaw(r);

  maybeStartKick(targetLeft, l, actualLeft, kickLeftUntilMs, lastKickLeftMs, kickLeftSign);
  maybeStartKick(targetRight, r, actualRight, kickRightUntilMs, lastKickRightMs, kickRightSign);

  targetLeft = l;
  targetRight = r;
  lastCommandMs = millis();
}

void softStop() {
  targetLeft = 0;
  targetRight = 0;
  lastCommandMs = millis();
}

void brakeStop() {
  targetLeft = 0;
  targetRight = 0;
  actualLeft = 0;
  actualRight = 0;
  kickLeftUntilMs = 0;
  kickRightUntilMs = 0;
  brakeUntilMs = millis() + BRAKE_PULSE_MS;
  lastCommandMs = millis();
}
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

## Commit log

2026-07-21 feat: add IMU-guided avoidance and point-cloud mapping
    [AM_HighTorqueAntiStall_500HzPWM_NoJumper_v4_for_x3.ino, M5_AM_SEN0628_3xSEN0628_v15.ino]
2026-07-21 feat: add BMA400 fusion, auto-converging calibration, and calibration telemetry
    - M5: read BMA400 (TCA CH0, Grove) and fuse its acceleration with the
    built-in IMU for the point-cloud viewer's dead reckoning; fix the M5
    IMU's own accel axis mapping (mount orientation was inverted).
    - M5: rework BtnB straight calibration to run multiple short passes per
    round, aggregate via median, and auto-repeat rounds until converged or
    a max-round cap, with clearer abort/no-space/cancel handling.
    - M5: stream calibration progress (round/pass/drift/trim) over the
    existing UDP point-cloud link so it's visible on the PC side too.
    - tools/point_cloud_viewer.py: bump protocol to v4, decode BMA400 acce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
    [AM_HighTorqueAntiStall_500HzPWM_NoJumper_v4_for_x3.ino, M5_AM_SEN0628_3xSEN0628_v15.ino]
2026-07-21 docs: add operation manual (手順書.md)
    Step-by-step guide from power-on through calibration, driving, and the
    point-cloud viewer, with an LCD-message reference table and a
    troubleshooting section, kept in sync with the v19 firmware behavior.
2026-07-23 feat: improve corridor avoidance and sensor safety
    [AM_HighTorqueAntiStall_500HzPWM_NoJumper_v4_for_x3.ino, M5_AM_SEN0628_3xSEN0628_v15.ino]
